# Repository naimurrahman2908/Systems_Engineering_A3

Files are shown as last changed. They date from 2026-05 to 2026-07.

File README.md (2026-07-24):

# 🤖 Line Following and Obstacle Avoidance Robot






---

## 📖 Project Overview

This repository contains the design, implementation, modelling, and testing of an autonomous **Line Following and Obstacle Avoidance Robot** developed as part of the **Systems Engineering** course at **Hochschule Hamm-Lippstadt (HSHL)**.

The robot autonomously follows a predefined black line using infrared (IR) sensors while detecting obstacles with ultrasonic sensors. The project combines embedded software, hardware integration, SysML modelling, and automated technical documentation using LaTeX.

---

## 👥 Team Members

| Member | Responsibility |
|---|---|
| **Naimur Rahman** | Introduction and Objectives |
| **Hany Chowdhury** | System Design and Engineering Approach |
| **Torikul Islam** | Hardware & Software Implementation, Simulation & Testing |
| **Adham Elsaygh** | Challenges and Solutions |

---

# 🎯 Project Objectives

The objectives of this project are to:

- Design an autonomous mobile robot capable of following a black line.
- Detect and avoid obstacles during navigation.
- Reacquire the line after obstacle avoidance.
- Perform an automatic 180° turn after detecting the second obstacle.
- Apply Systems Engineering principles throughout development.
- Model the complete system using SysML.
- Validate the final prototype through experimental testing.

---

# ⭐ Features

- Autonomous Line Following
- Obstacle Detection
- Obstacle Avoidance
- Automatic Line Reacquisition
- 180° Turnaround
- PWM Motor Speed Control
- Embedded Arduino Software
- SysML-Based System Design
- Automated LaTeX Report Generation

---

# 🏗 System Architecture

The robot consists of four major subsystems.

| Subsystem | Components | Function |
|---|---|---|
| Sensing | IR Sensors, Ultrasonic Sensors | Detects the line and obstacles |
| Control | Arduino Uno | Processes sensor data |
| Actuation | L293D Driver, DC Motors | Controls movement |
| Power | 12V Battery | Powers the robot |

---

# 🔧 Hardware Components

- Arduino Uno
- 2 × IR Line Sensors
- 2 × HC-SR04 Ultrasonic Sensors
- L293D Motor Driver
- 2 × DC Geared Motors
- Breadboard
- Wooden Chassis
- 12 V Battery
- Wheels

---

# 🔌 Wiring Connections

## 🔵 Arduino UNO Pin Configuration

| Component | Arduino Pin | Description |
|---|---|---|
| Left IR Sensor | D2 | Left line detection |
| Right IR Sensor | D12 | Right line detection |
| Left Ultrasonic Trigger | D13 | Trigger signal |
| Left Ultrasonic Echo | D4 | Echo signal |
| Right Ultrasonic Trigger | D6 | Trigger signal |
| Right Ultrasonic Echo | D7 | Echo signal |
| Left Motor Enable (ENA) | D3 (PWM) | Speed control |
| Left Motor IN1 | D8 | Motor direction |
| Left Motor IN2 | D9 | Motor direction |
| Right Motor Enable (ENB) | D5 (PWM) | Speed control |
| Right Motor IN3 | D10 | Motor direction |
| Right Motor IN4 | D11 | Motor direction |

---

## ⚡ Power Connections

| Connection | Description |
|---|---|
| 12 V Battery → Motor Driver | Main power supply |
| Motor Driver 5 V → Arduino UNO | Regulated controller power |
| Arduino 5 V → Sensors | Sensor power supply |
| Common Ground | Shared by all components |

> **Important:** All electronic modules share a common ground to ensure stable operation.

---

# 💻 Software Components

- Arduino IDE
- Embedded C++
- Line Following Algorithm
- Obstacle Detection Algorithm
- Obstacle Avoidance Routine
- Line Reacquisition Logic
- Motor Control Functions

---

# 🔄 Robot Operation

The robot operates according to the following sequence:

1. Detect the black line using IR sensors.
2. Read sensor values.
3. Calculate steering direction.
4. Control both motors independently.
5. Continuously monitor obstacles.
6. Detect the first obstacle.
7. Execute obstacle avoidance.
8. Search for and reacquire the line.
9. Continue navigation.
10. Detect the second obstacle.
11. Perform a 180° turn.
12. Continue autonomous operation.

---

# 📊 SysML Models

The project documentation includes:

- Block Definition Diagram (BDD)
- Internal Block Diagram (IBD)
- Use Case Diagram
- Activity Diagram
- Sequence Diagram
- State Machine Diagram
- Package Diagram

---

# 🧪 Testing

The robot was experimentally evaluated using a custom test track with a **2.5 cm black line**, including gentle and sharp curves as well as two obstacles.

### Testing Included

- IR Sensor Validation
- Ultrasonic Sensor Validation
- Motor Verification
- Line Following
- Sharp Curve Tracking
- Gentle Curve Tracking
- Obstacle Avoidance
- Line Reacquisition
- 180° Turn
- Full System Integration

---

## 📈 Performance Summary

| Test | Result |
|---|---|
| Line Following | ✅ Successful |
| Gentle Curves | ✅ Successful |
| Sharp Curves | ✅ Successful |
| First Obstacle Detection | ✅ Successful |
| Obstacle Avoidance | ✅ Successful |
| Line Reacquisition | ✅ Successful |
| Second Obstacle Detection | ✅ Successful |
| 180° Turn | ✅ Successful |
| Complete Trials | **10 / 10** |
| Overall Success Rate | **100%** |

---

# 🛠 Technologies Used

- Arduino IDE
- C++
- GitHub
- GitHub Actions
- LaTeX (IEEE Format)
- SysML
- Visual Paradigm
- Tinkercad

---

# 📁 Repository Structure

```text
Systems_Engineering_A3/
│
├── Codes/
│
├── Prototype_Design/
│
├── SysML_Diagrams/
│
├── Tinkercad_Design/
│
└── LineFollowingRobot_Report/
    ├── figures/
    ├── sections/
    ├── main.tex
    └── report.pdf
```

---

# 📄 Report Compilation

The project documentation is written in **LaTeX** using the IEEE Conference format.

GitHub Actions automatically:

- Builds the report
- Compiles the PDF
- Commits the latest report
- Keeps documentation up to date

---

# 📚 Latest Report

The latest IEEE report is available below.

➡️ **[Download PDF Report](./LineFollowingRobot_Report/report.pdf)**

---

# 🚀 Future Improvements

Potential future enhancements include:

- PID Controller
- Wireless Communication
- Bluetooth Monitoring
- Wi-Fi Connectivity
- Camera-Based Navigation
- Machine Learning
- Real-Time Telemetry
- Improved Chassis Design
- Battery Monitoring

---

# 🎓 Course Information

| Item | Details |
|---|---|
| Course | Systems Engineering |
| Degree | Electronic Engineering |
| University | Hochschule Hamm-Lippstadt |
| Semester | Summer Semester 2026 |

---

# 📜 License

This repository was developed for academic purposes as part of the **Systems Engineering** course at **Hochschule Hamm-Lippstadt**.

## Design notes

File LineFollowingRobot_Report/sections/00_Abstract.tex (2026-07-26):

\begin{abstract}
This paper presents a low-cost line-following and obstacle-avoidance robot built on an Arduino Uno. Two IR sensors enable line tracking, while two HC-SR04 ultrasonic sensors handle obstacle detection; an L293D motor driver controls the two DC motors. Prior to construction, a systems engineering approach using SysML diagrams (block definition, internal block, activity, sequence, use case, and state machine) modeled the robot's structure and behavior. The design follows a track, avoids the first detected obstacle, then performs a 180° turn at a second obstacle before retracing the line in reverse. Testing on a custom track with curves and obstacles yielded a 100 percent success rate across 10 trials, confirming reliable performance.
\end{abstract}

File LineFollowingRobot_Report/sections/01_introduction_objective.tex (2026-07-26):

\section{Introduction and Objective}
\label{sec:introduction and objective}
\subsection{Introduction}

Automated Guided Vehicles (AGVs) are smart, driverless vehicles that bring the speed and precision of modern automation to material handling. By using advanced embedded systems to navigate safely and adapt in real time, they turn manual logistics into a predictable, data-driven backbone for Industry 4.0 [1, 2]. 

Line following and collision avoidance serve as the fundamental navigation and safety pillars. Together, these embedded subsystems ensure the AGV can optimize space by working seamlessly alongside human workers while strictly complying with industrial safety standards like ISO 3691-4. 

This project focuses on the systems engineering, prototyping, and development of a compact, microcontroller-driven autonomous vehicle designed for precise trajectory tracking and proactive collision mitigation. 

\subsection{Objective}

The primary goal of this project is to implement, test, and validate a working prototype of an autonomous mobile vehicle using model-based prototyping principles. To meet the course milestones, the system must achieve the following specific technical objectives:
\begin{itemize}
    \item {Line Following:} Use a set of infrared (IR) sensors and standard if-else logic to control the motors so the car cleanly follows a track line.
    \item {Obstacle Detection and Avoidance:} Integrate a pair of ultrasonic sensors to monitor front proximity metrics and implement a maneuver sequence to safely bypass detected obstructions before reacquiring the primary track line.
    \item {Secondary Obstacle Detection and Turnaround:} Program the car to use its front ultrasonic sensors to detect a second obstacle along the path, stop moving forward, spin 180 degrees on the spot, and follow the track back in the opposite direction.
    \item {Power and Motor Integration:} Wire the hardware so that a motor controller takes a 12V battery source, drops it down to 5V to safely power the Arduino, and handles the high-current demands of the DC motors.
\end{itemize}

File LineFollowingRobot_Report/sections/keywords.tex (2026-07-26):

\begin{IEEEkeywords}
    Line follower robot, IR sensor, Ultrasonic sensor, Arduino, Obstacle avoidance, DC motor
\end{IEEEkeywords}

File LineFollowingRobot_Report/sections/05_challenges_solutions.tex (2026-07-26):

\section{Challenges and Solutions}
\label{sec:challenges_solutions}
During the engineering and prototyping phases, several technical challenges were encountered across the hardware and software subsystems. 
These obstacles were systematically resolved through testing, software adjustments, and control refinements.  

A. Motor Speed Inconsistency and Straight-Line Drift
A primary physical challenge involved mechanical and electrical variances between the two DC motors. When driven with identical pulse-width modulation (PWM) signals, differences in motor resistance and internal gear friction caused the robot to drift off course rather than moving straight.  

Solution: To achieve balanced linear movement, a software calibration procedure was performed using trial and error. By iteratively tuning and assigning individual offset PWM values to each motor, the rotational speeds were balanced to ensure straight-line movement.

B. Track Detection Strategy
During line-following testing, initial attempts were made to navigate by tracking the white boundary outline surrounding the black track. However, this approach resulted in inconsistent sensor readings. Testing confirmed that tracking the solid black line directly produced significantly better results.

Solution: The control logic and tracking strategy were reconfigured to target the solid black line directly. This adjustment provided higher contrast for the infrared sensors, leading to more reliable line tracking 
and smoother steering responses.

C. Ultrasonic Sensor Noise and Ghost Obstacles
During proximity measurement, the HC-SR04 ultrasonic sensors occasionally received false echo reflections from surrounding walls and non-target surfaces. This noise created "ghost obstacles," resulting in false-positive detections that caused the robot to stop prematurely.

Solution: Software-level signal filtering was integrated into the obstacle-detection routine. The control algorithm was programmed to prouduce 2 consecutive range readings before triggering an action, ensuring avoidance maneuvers were only executed when a real obstacle was confirmed.

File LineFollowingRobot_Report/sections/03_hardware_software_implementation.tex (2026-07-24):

\section{Hardware Software Implementation}
\label{sec:hardware_software_implementation}

\subsection{Hardware Implementation}

The developed prototype consists of a compact autonomous mobile robot capable of line following and obstacle avoidance. The system integrates sensing, control, actuation, and power management into a single embedded platform. Figure~\ref{fig:robot} shows the completed robot prototype used during implementation and testing.

The Arduino Uno microcontroller serves as the central controller of the robot. It continuously receives data from two infrared (IR) sensors and two HC-SR04 ultrasonic sensors, processes the sensor information, and generates motor control commands. The IR sensors are mounted at the front of the robot to detect the black line, while the ultrasonic sensors continuously monitor the distance to obstacles during navigation.

An L293D motor driver is used to control two DC geared motors. The motor driver receives PWM signals from the Arduino and regulates the speed and direction of both motors. To compensate for mechanical differences between the motors, calibrated PWM values were applied to obtain stable straight-line movement.

The complete system is powered by a 12\,V battery. The motor driver supplies a regulated 5\,V output to power the Arduino Uno and the connected sensors. This configuration provides a simple and reliable power distribution while maintaining stable operation of both the electronic and mechanical components.

The electronic components are mounted on a lightweight wooden chassis using a breadboard for rapid prototyping. This modular arrangement simplifies wiring, maintenance, and future hardware modifications.

\begin{table}[ht]
\caption{Hardware Components}
\centering
\begin{tabular}{lll}
\hline
\textbf{Component} & \textbf{Qty} & \textbf{Purpose} \\
\hline
Arduino Uno & 1 & Main controller \\
L293D Motor Driver & 1 & Motor control \\
DC Motors & 2 & Robot movement \\
IR Sensors & 2 & Line detection \\
HC-SR04 Sensors & 2 & Obstacle detection \\
Breadboard & 1 & Circuit prototyping \\
12\,V Battery & 1 & Power supply \\
Wooden Chassis & 1 & Mechanical support \\
\hline
\end{tabular}
\label{tab:hardware}
\end{table}

\begin{figure}[ht]
\centering
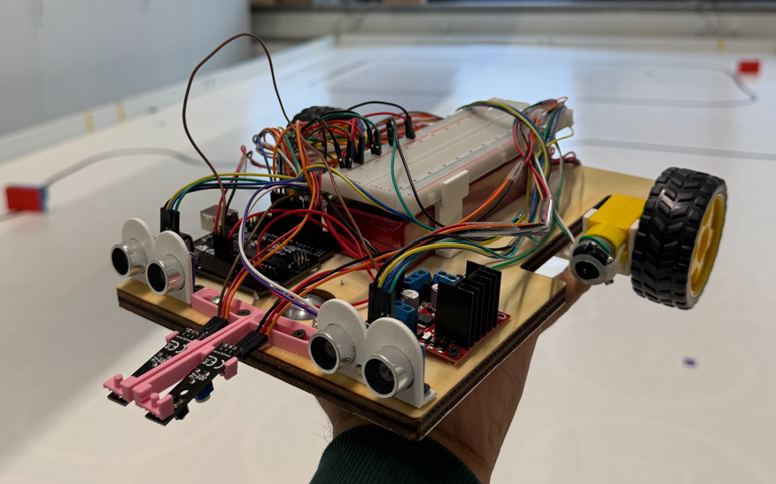
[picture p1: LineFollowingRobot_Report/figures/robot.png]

\caption{Final hardware prototype of the autonomous line-following and obstacle-avoidance robot.}
\label{fig:robot}
\end{figure}

\subsection{Software Implementation}

The control software was developed using the Arduino Integrated Development Environment (Arduino IDE) in C++. A modular programming approach was adopted to separate sensor acquisition, motor control, obstacle detection, and navigation into independent software functions. This improves readability, simplifies debugging, and allows future system extensions.

During initialization, the Arduino configures all digital input and output pins, initializes the infrared and ultrasonic sensors, and enables the motor driver. After initialization, the software repeatedly executes the main control loop throughout the robot's operation.

The first stage of the control algorithm continuously checks the ultrasonic sensors for nearby obstacles. When an obstacle is detected within the predefined safety distance, the robot immediately stops and confirms the measurement before executing the obstacle avoidance routine.

If no obstacle is detected, the robot performs line following using the two infrared sensors. Based on the sensor readings, the controller determines whether the robot should move forward, turn left, or turn right. Independent PWM control of the two motors enables smooth steering corrections while following the track.

To improve navigation reliability, the software stores the previous movement direction. If both infrared sensors temporarily lose the line, the robot searches in the last known direction until the track is detected again. After avoiding an obstacle, the robot continues searching until the line is reacquired before resuming normal navigation.

Overall, the implemented software provides reliable autonomous operation while maintaining a computationally efficient control strategy suitable for embedded systems.

\subsection{Hardware--Software Integration}

The hardware and software operate together as a closed-loop embedded system. Sensor information collected by the infrared and ultrasonic sensors is processed by the Arduino Uno, which determines the appropriate movement commands. These commands are transmitted to the L293D motor driver, which controls the speed and direction of the two DC motors.

The continuous interaction between sensing, processing, and actuation enables the robot to follow a predefined path, detect obstacles, execute avoidance manoeuvres, and return to the original track without external intervention. The implementation demonstrates that reliable autonomous behaviour can be achieved using low-cost hardware combined with an efficient embedded control algorithm.

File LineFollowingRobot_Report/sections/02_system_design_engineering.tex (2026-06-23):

\section{System Design and Engineering Approach}
\label{sec:system_design_engineering}
\subsection{System Overview}

The Line Following Robot is an autonomous system designed to follow a predefined path while detecting obstacles during operation. The system combines sensing, control, and actuation components to achieve reliable navigation. A systems engineering approach was applied throughout the project to identify requirements, define subsystem interactions, and develop an organized system architecture before implementation.

The robot consists of four main subsystems: the sensing subsystem, control subsystem, actuation subsystem, and power subsystem. These subsystems work together to support autonomous movement and obstacle detection.

\subsection{System Architecture}

A Block Definition Diagram (BDD) was created to represent the main components of the robot and their relationships. The diagram provides an overview of how the sensing, control, movement, and power elements are organized within the system.

\begin{figure}[htbp]
\centering
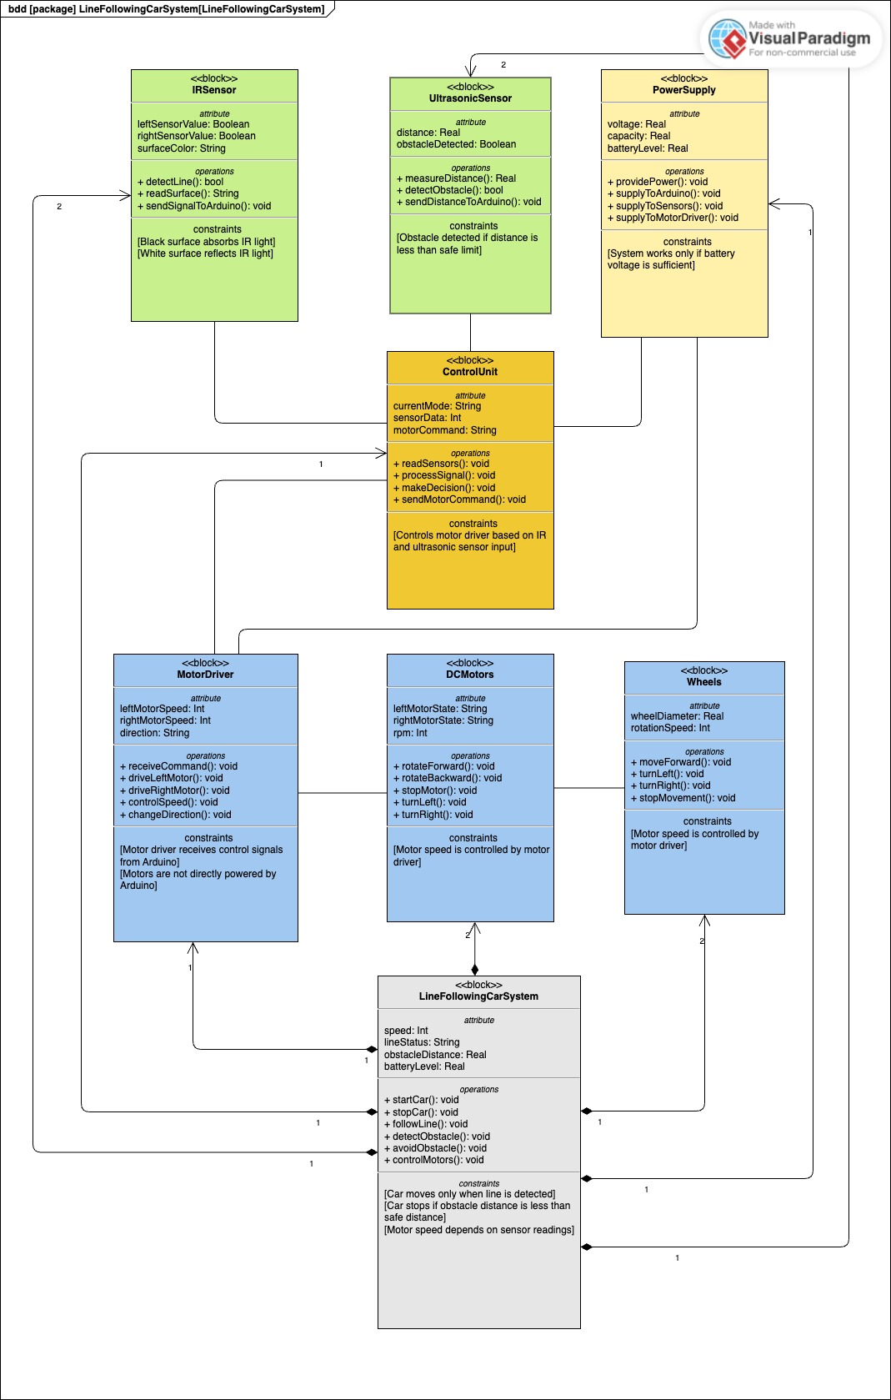
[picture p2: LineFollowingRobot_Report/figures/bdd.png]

\caption{Block Definition Diagram of the Line Following Robot}
\label{fig:bdd}
\end{figure}
\FloatBarrier

The sensing subsystem includes infrared (IR) sensors for line detection and ultrasonic sensors for obstacle detection. The control subsystem is based on the Arduino Uno microcontroller, which processes sensor information and determines the required motor actions. The actuation subsystem consists of the L293D motor driver and two DC motors that provide movement. The power subsystem supplies electrical energy to all hardware components.

\subsection{Internal Component Interaction}

An Internal Block Diagram (IBD) was developed to illustrate the connections and interactions between system components. The diagram shows how information and control signals are exchanged within the robot.

\begin{figure}[htbp]
\centering
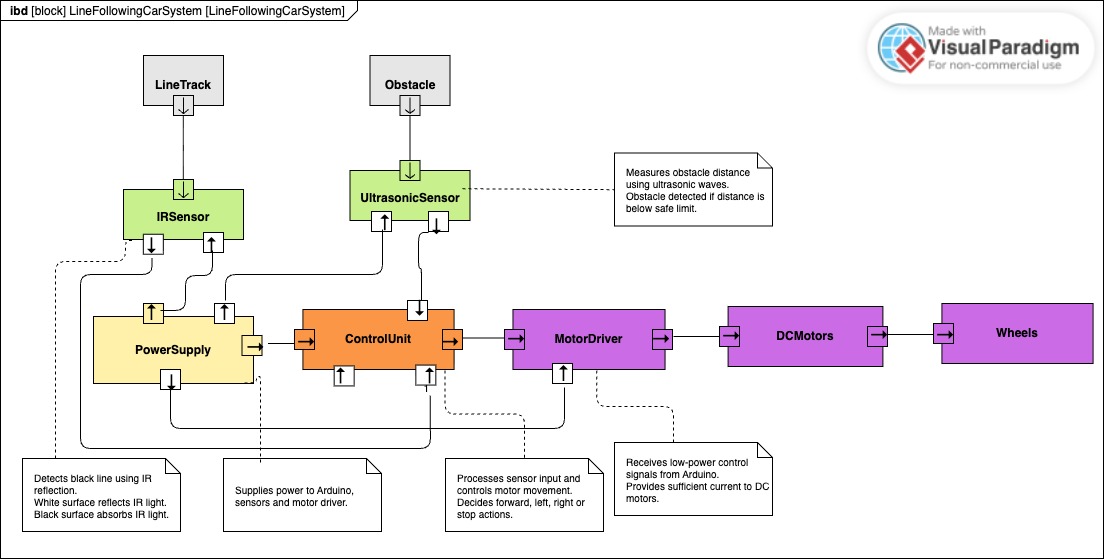
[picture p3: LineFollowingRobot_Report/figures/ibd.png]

\caption{Internal Block Diagram}
\label{fig:ibd}
\end{figure}
\FloatBarrier

The IR sensors continuously monitor the line position and send data to the Arduino controller. At the same time, the ultrasonic sensors measure the distance to nearby obstacles. Based on these inputs, the Arduino generates appropriate control signals for the motor driver, which adjusts the speed and direction of the motors.

\subsection{Functional Behaviour}

The behaviour of the robot was analysed using system modelling techniques. An Activity Diagram was created to describe the overall operational workflow.

\begin{figure}[htbp]
\centering
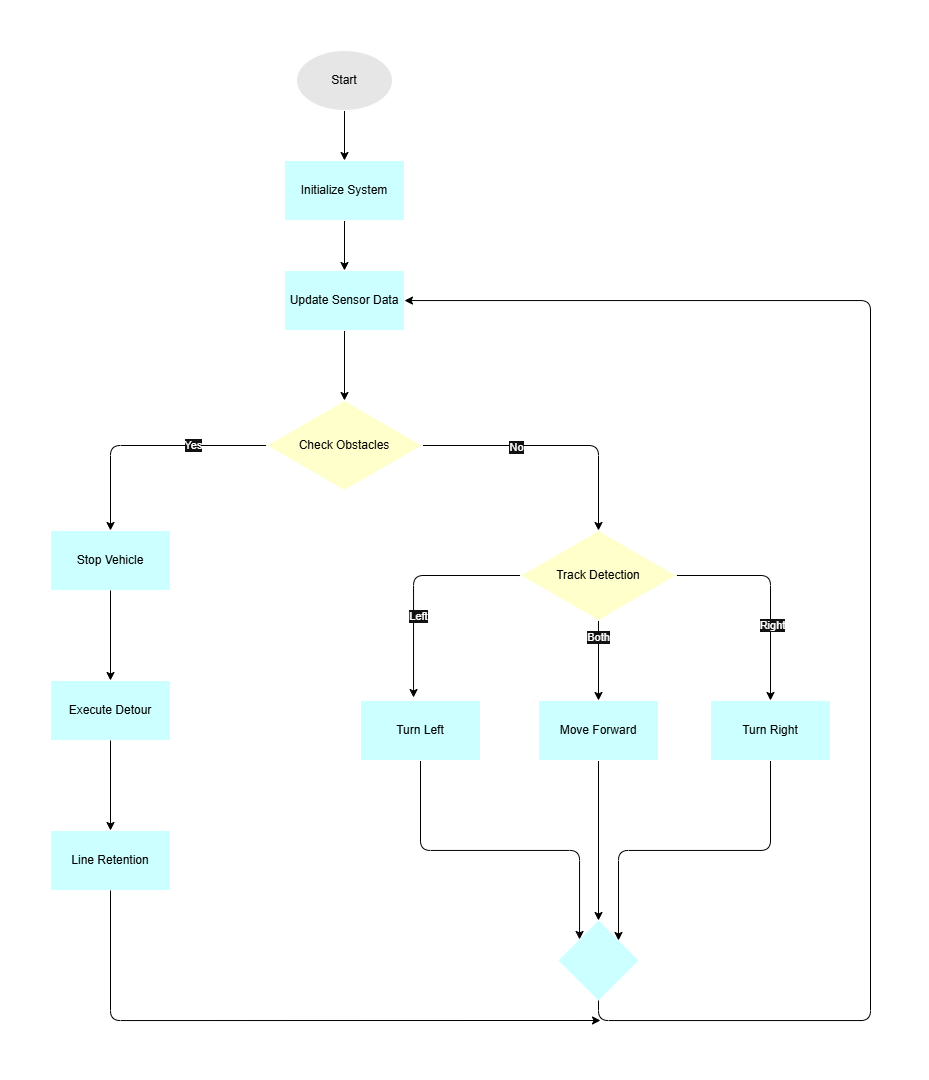
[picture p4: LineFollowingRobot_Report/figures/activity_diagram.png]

\caption{Activity Diagram}
\label{fig:activity}
\end{figure}
\FloatBarrier

The process begins with system initialization. The robot then continuously reads sensor data, evaluates the position of the line and the presence of obstacles, determines the required action, and updates motor commands. This cycle is repeated throughout operation.

A Sequence Diagram was also developed to represent the interaction between system components during robot operation.

\begin{figure}[htbp]
\centering
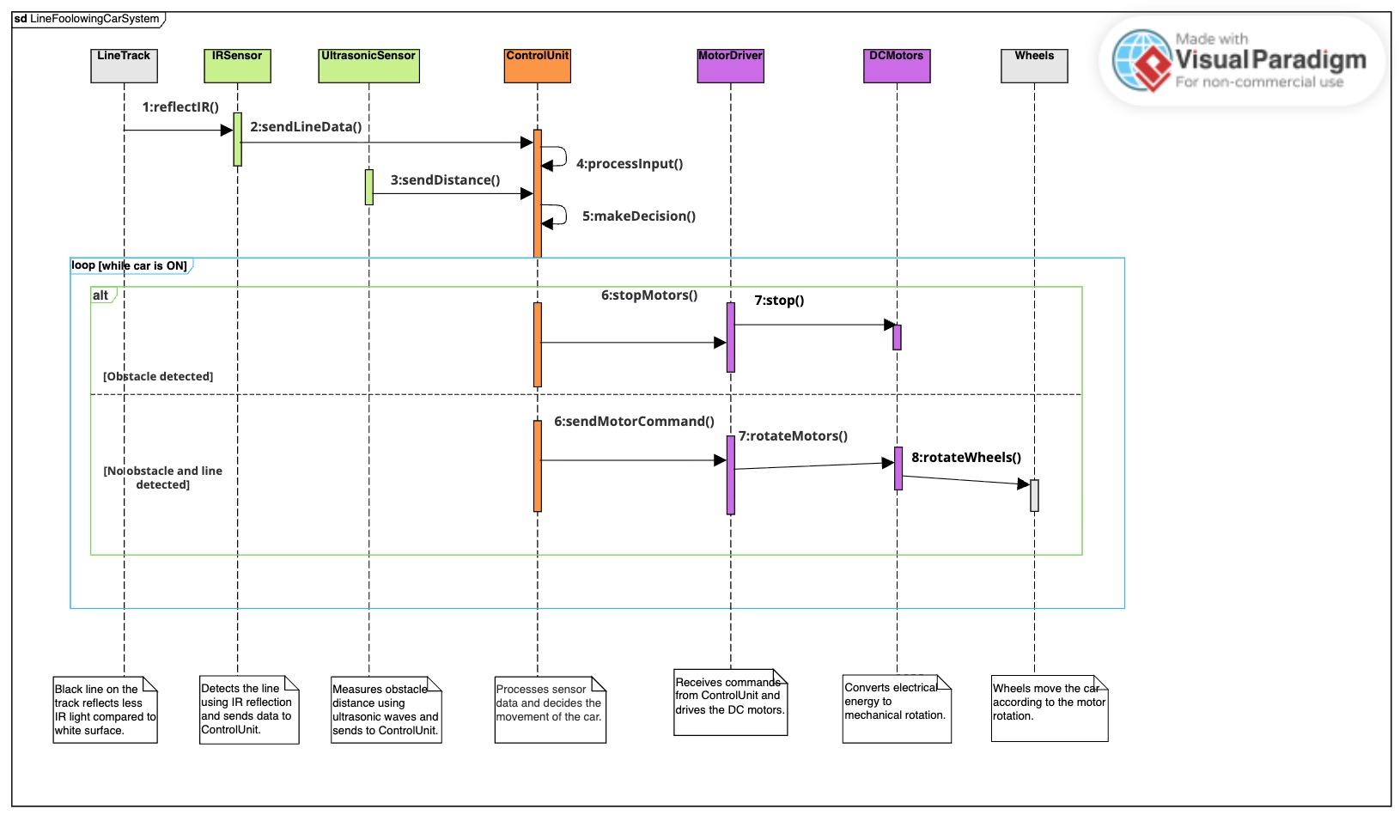
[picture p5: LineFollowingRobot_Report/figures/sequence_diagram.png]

\caption{Sequence Diagram}
\label{fig:sequence}
\end{figure}
\FloatBarrier

The sequence diagram illustrates how information is exchanged between the sensors, controller, and actuators during line-following and obstacle-detection activities.

\subsection{Use Case Analysis}

A Use Case Diagram was developed to identify the main functions of the robot from the user’s perspective.

\begin{figure}[htbp]
\centering
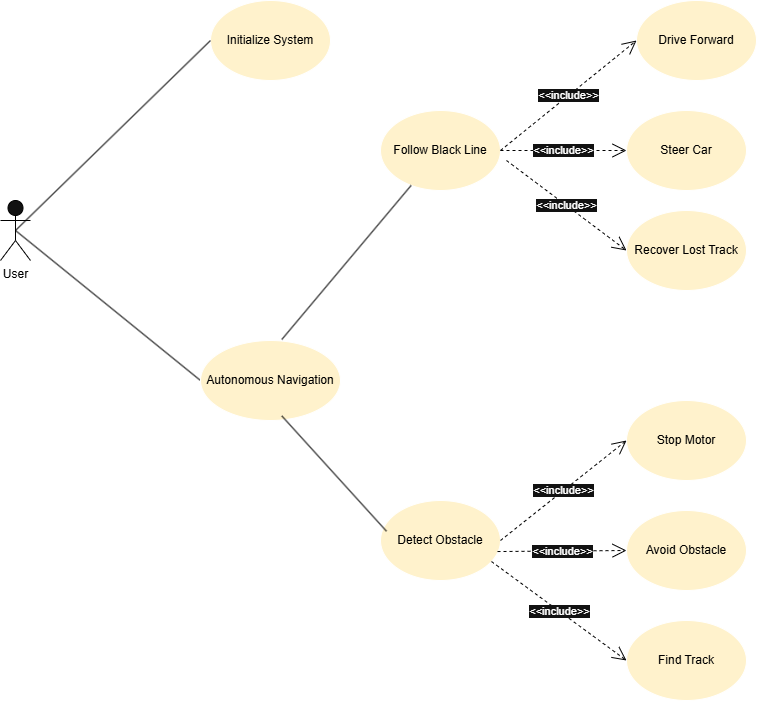
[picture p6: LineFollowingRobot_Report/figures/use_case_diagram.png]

\caption{Use Case Diagram}
\label{fig:usecase}
\end{figure}
\FloatBarrier

The main use cases include starting the robot, following the line, detecting obstacles, controlling movement, and stopping the robot. These functions represent the primary operational requirements of the system.

\subsection{System States}

A State Machine Diagram was created to model the different operational states of the robot.

\begin{figure}[htbp]
\centering
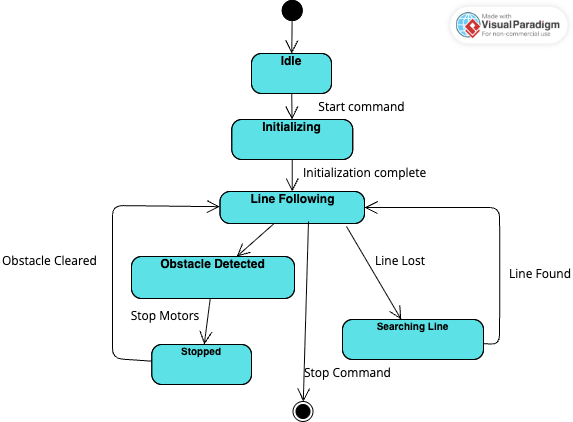
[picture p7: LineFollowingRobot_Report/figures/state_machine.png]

\caption{State Machine Diagram}
\label{fig:state}
\end{figure}
%\FloatBarrier

The robot initially remains in the Idle state. Once activated, it transitions to the Line Following state. When an obstacle is detected, the system moves to the Obstacle Detected state and performs a stop or avoidance action. After the obstacle is cleared, the robot returns to normal operation.

\subsection{Design Decisions}

Several design decisions were made during the development of the prototype. The Arduino Uno was selected because it is easy to program, widely supported, and compatible with various sensors and motor drivers. IR sensors were chosen for accurate line detection, while ultrasonic sensors were used to provide reliable obstacle detection. The L293D motor driver was selected because it allows simple and effective control of two DC motors.

The use of SysML diagrams improved system understanding by providing both structural and behavioural views of the robot. These models supported the implementation process and helped ensure consistency between system requirements and the final prototype design.

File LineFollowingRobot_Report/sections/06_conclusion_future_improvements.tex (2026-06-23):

\section{Conclusion and Future Improvements}
\label{sec:conclusion_future_improvements}
\subsection{Conclusion}

This project successfully demonstrated the design and development of a Line Following Robot capable of autonomous navigation and obstacle detection. By integrating infrared sensors, ultrasonic sensors, an Arduino Uno microcontroller, and a motor control system, the robot was able to follow a predefined path while responding to environmental conditions.

A systems engineering approach was applied throughout the project to support requirement identification, system modelling, implementation, and testing. The use of SysML diagrams provided a clear representation of both the structural and behavioural aspects of the system, helping to improve understanding of component interactions and overall system functionality.

The testing results showed that the robot was able to perform the intended line-following and obstacle-detection tasks under normal operating conditions. Therefore, the project achieved its primary objective of developing a functional robotic prototype while applying key systems engineering principles.

\subsection{Future Improvements}

Although the prototype met the project requirements, several improvements could be implemented in future developments. One possible enhancement is the integration of a PID control algorithm to improve movement accuracy and provide smoother line-following performance. Additional infrared sensors could also be incorporated to increase detection reliability, particularly when navigating sharp curves or complex paths.

The mechanical design could be further optimized by improving chassis stability, wheel alignment, and component placement. These modifications may contribute to better overall performance and durability of the robot.

Furthermore, wireless communication technologies such as Bluetooth or Wi-Fi could be added to enable remote monitoring and control. Future versions may also incorporate camera-based vision systems or machine learning techniques to support more advanced navigation and obstacle-avoidance capabilities.

Overall, the proposed improvements would increase the robot’s accuracy, adaptability, and functionality, making it more suitable for complex autonomous applications.

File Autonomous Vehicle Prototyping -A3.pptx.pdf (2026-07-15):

# Line Following & Obstacle Avoidance Control

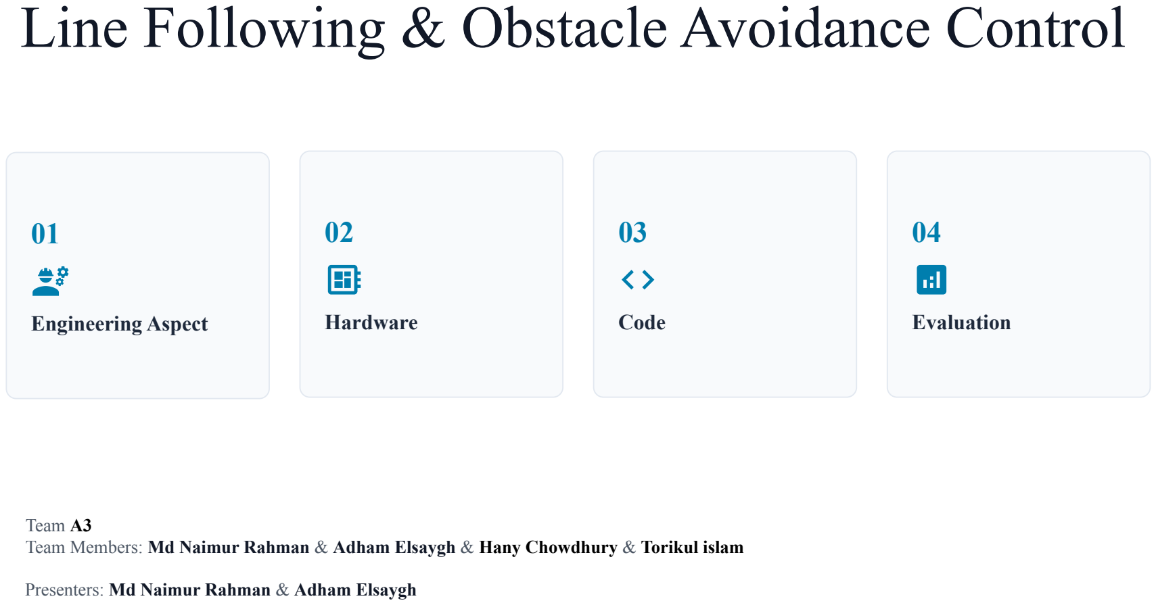
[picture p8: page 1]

01

## Engineering Aspect

02

## Hardware

03

## Code

04

## Evaluation

Presenters: Md Naimur Rahman & Adham Elsaygh

Team A3
Team Members: Md Naimur Rahman & Adham Elsaygh & Hany Chowdhury & Torikul islam

# Systems Engineering Aspect

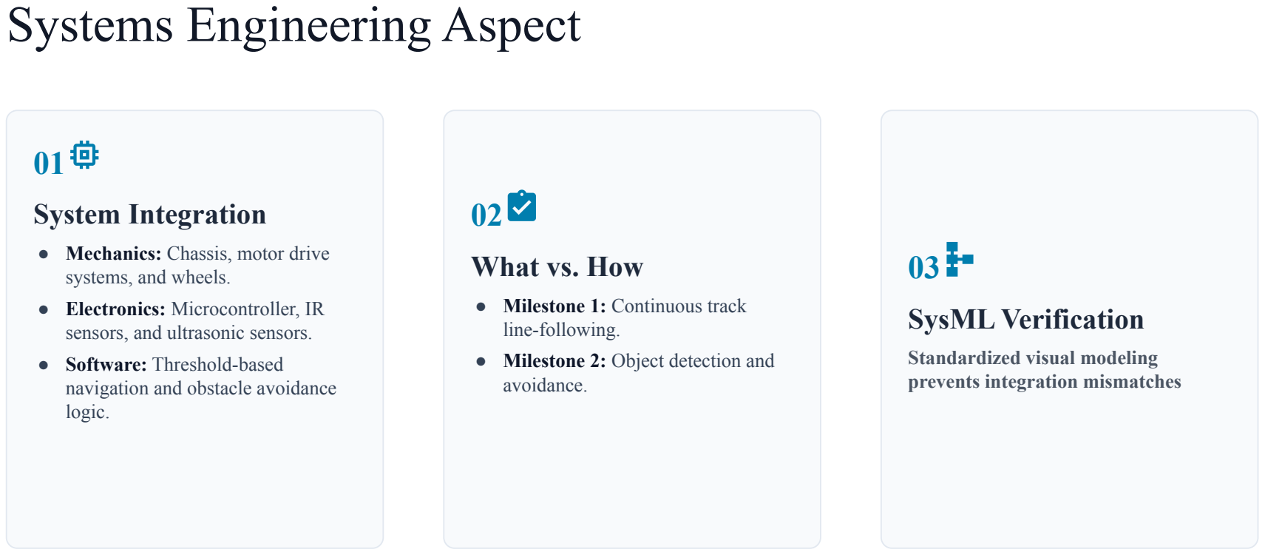
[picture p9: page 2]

01

## System Integration

- Mechanics: Chassis, motor drive systems, and wheels.
- Electronics: Microcontroller, IR sensors, and ultrasonic sensors.
- Software: Threshold-based navigation and obstacle avoidance logic.

02

## What vs. How

- Milestone 1: Continuous track line-following.
- Milestone 2: Object detection and avoidance.

03

## SysML Verification

Standardized visual modeling prevents integration mismatches

# Hardware Setup & Integration

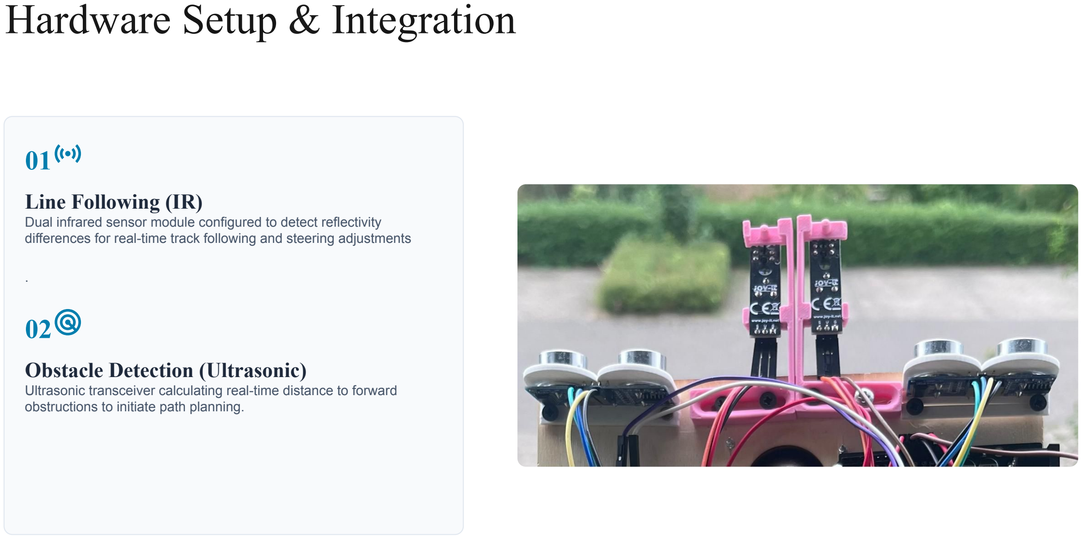
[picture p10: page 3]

01

## Line Following (IR)

Dual infrared sensor module configured to detect reflectivity differences for real-time track following and steering adjustments

02

## Obstacle Detection (Ultrasonic)

Ultrasonic transceiver calculating real-time distance to forward obstructions to initiate path planning.

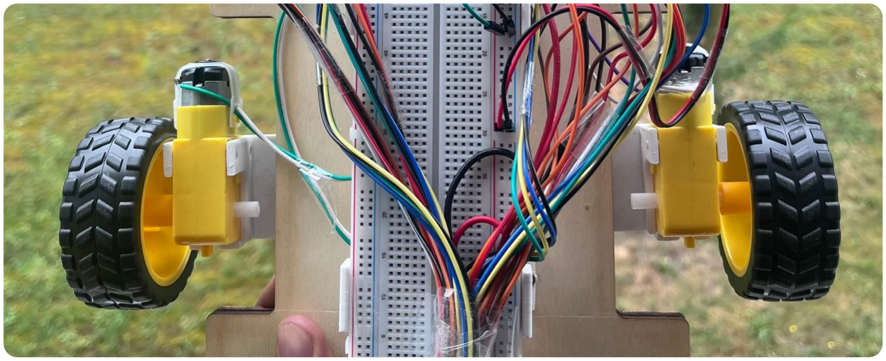
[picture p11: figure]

03

## Motor Setup

High-torque DC motors configured for precise speed and directional mobility.

04

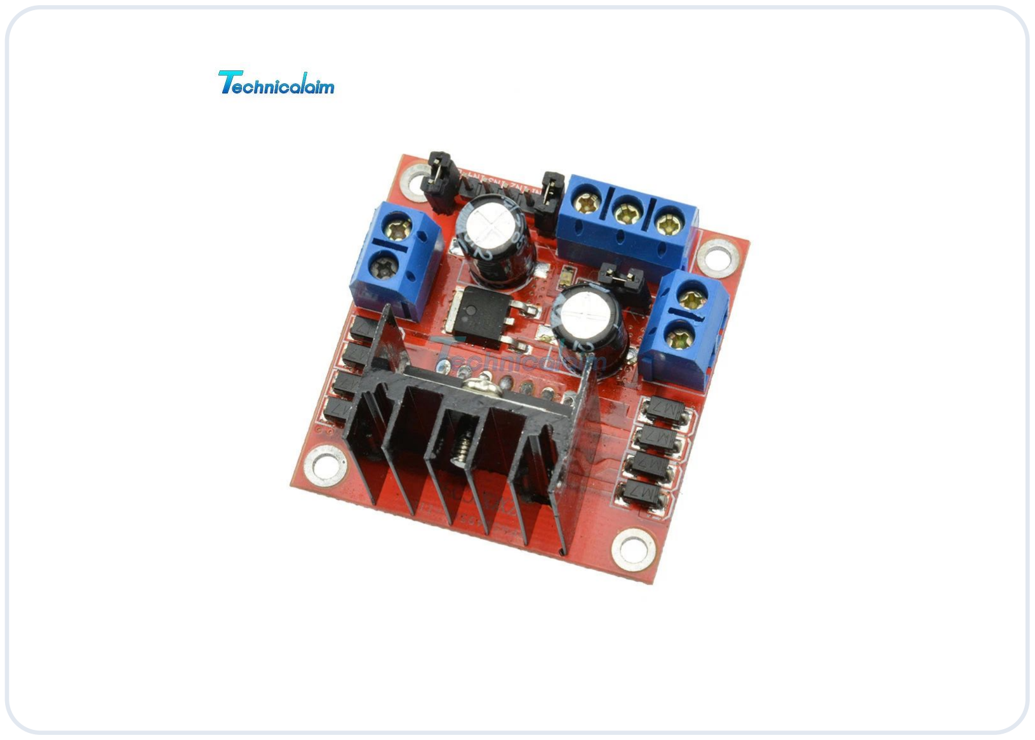
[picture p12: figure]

## Motor Driver (L298N)

Dual-channel H-bridge controller managing voltage and direction for the drive system.

05

## Voltage Regulation Flow

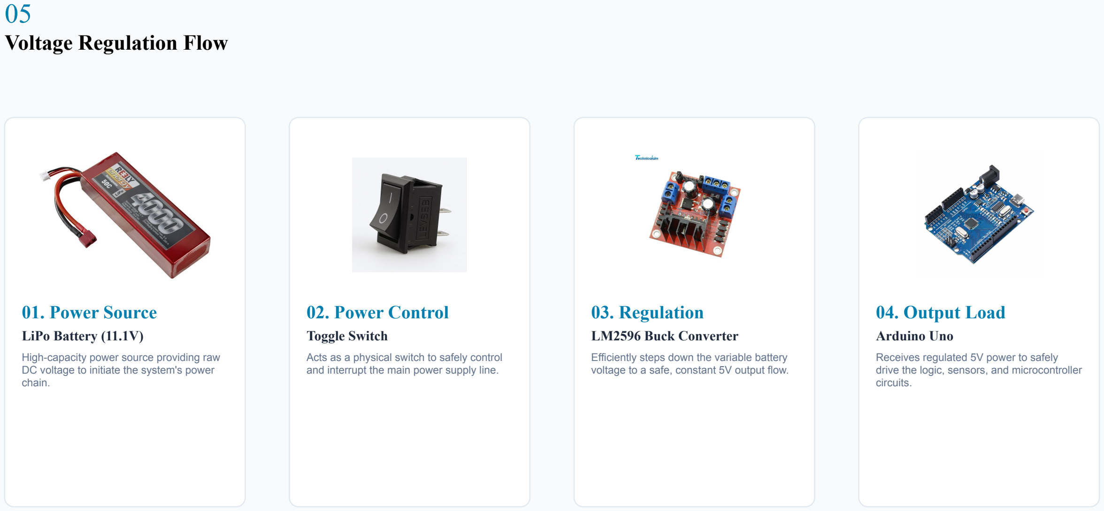
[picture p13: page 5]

### 01. Power Source

LiPo Battery (11.1V)

High-capacity power source providing raw DC voltage to initiate the system's power chain.

### 02. Power Control

Toggle Switch

Acts as a physical switch to safely control and interrupt the main power supply line.

### 03. Regulation

LM2596 Buck Converter

Efficiently steps down the variable battery voltage to a safe, constant 5V output flow.

### 04. Output Load

Arduino Uno

Receives regulated 5V power to safely drive the logic, sensors, and microcontroller circuits.

# Code Implementation

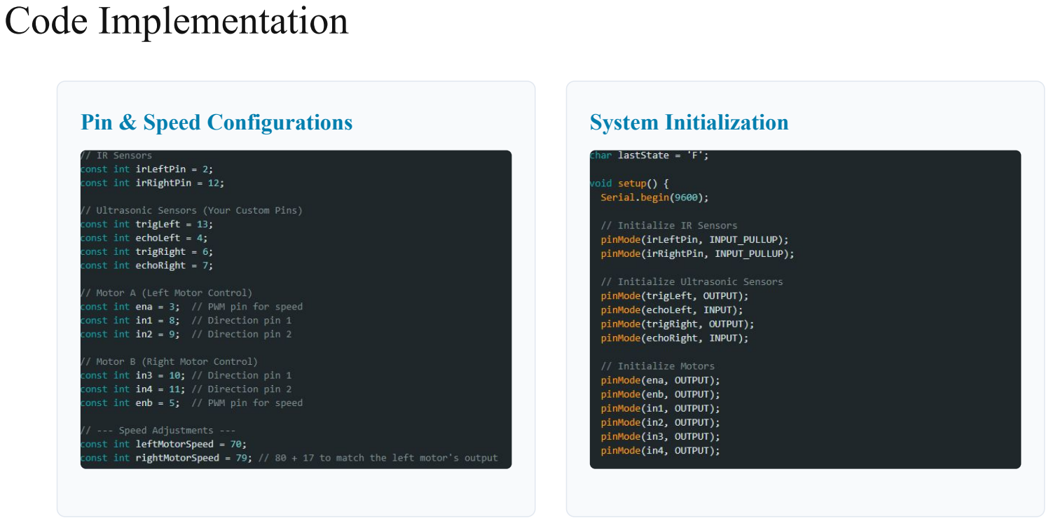
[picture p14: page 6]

Pin & Speed Configurations | System Initialization

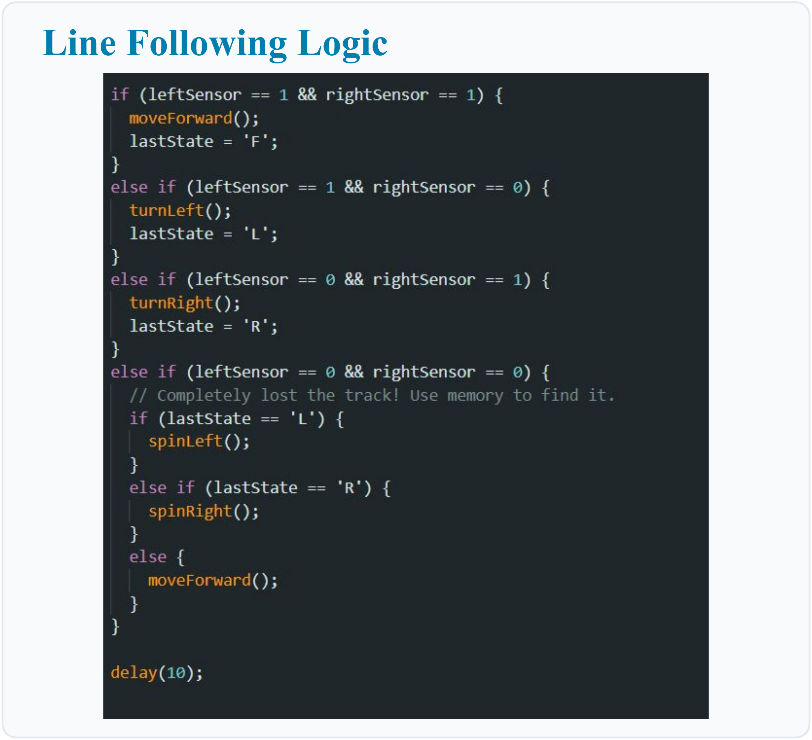
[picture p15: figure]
Line Following Logic

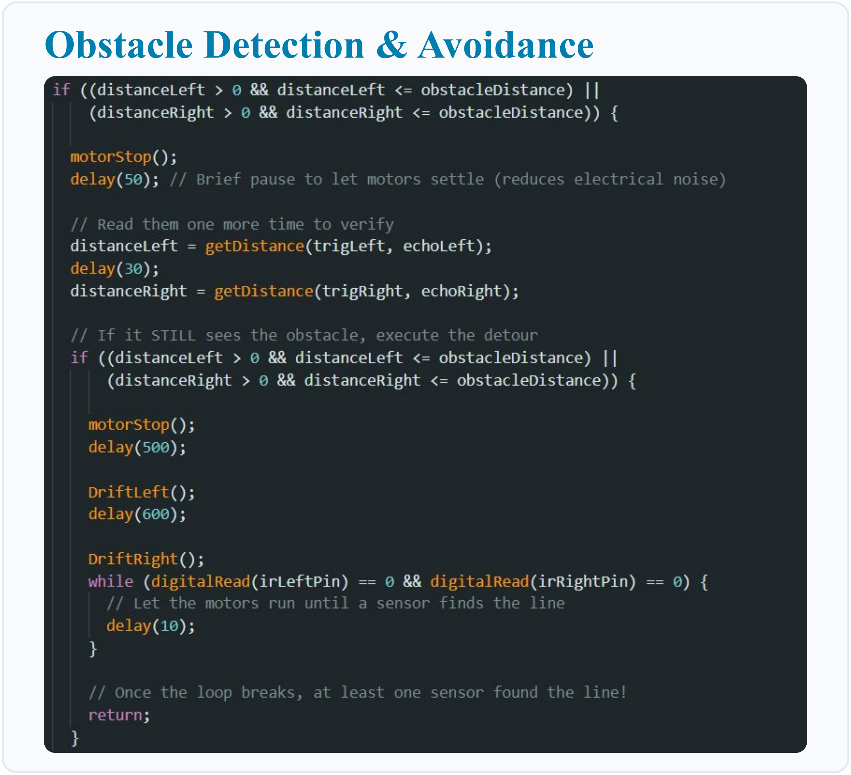
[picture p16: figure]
Obstacle Detection & Avoidance

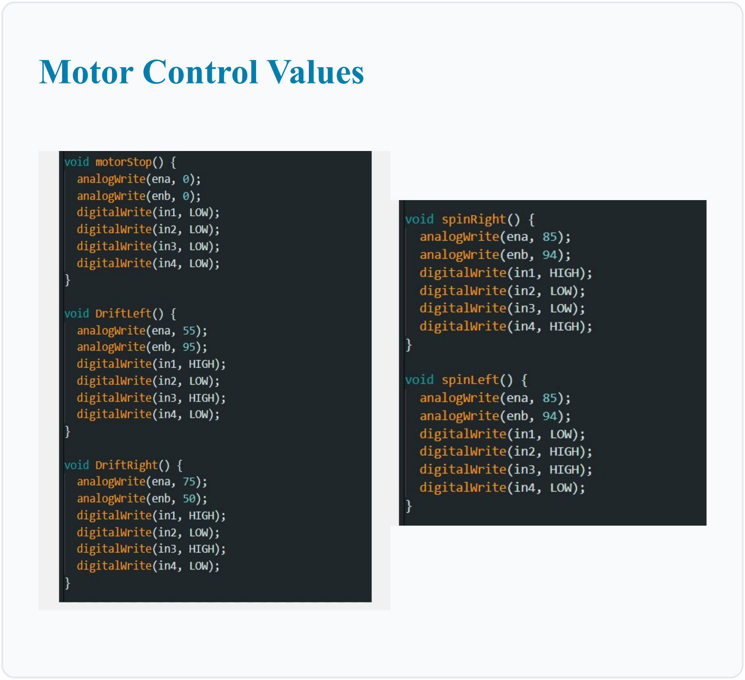
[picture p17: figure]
Motor Control Values

# Testing and Evaluation

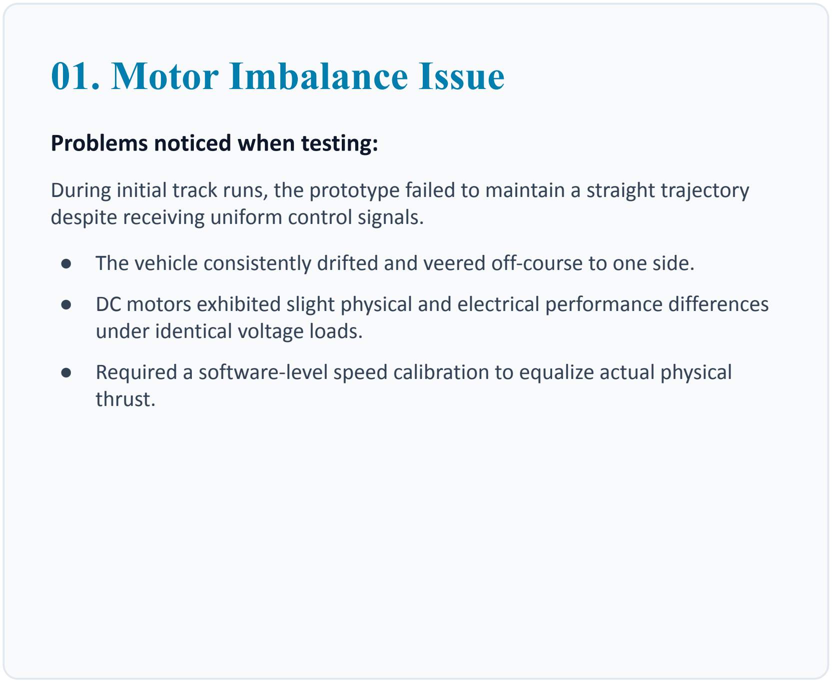
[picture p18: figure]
01. Motor Imbalance Issue; Problems noticed when testing:; despite receiving uniform control signals.; under identical voltage loads.; thrust.

During initial track runs, the prototype failed to maintain a straight trajectory

- The vehicle consistently drifted and veered off-course to one side.
- DC motors exhibited slight physical and electrical performance differences
- Required a software-level speed calibration to equalize actual physical

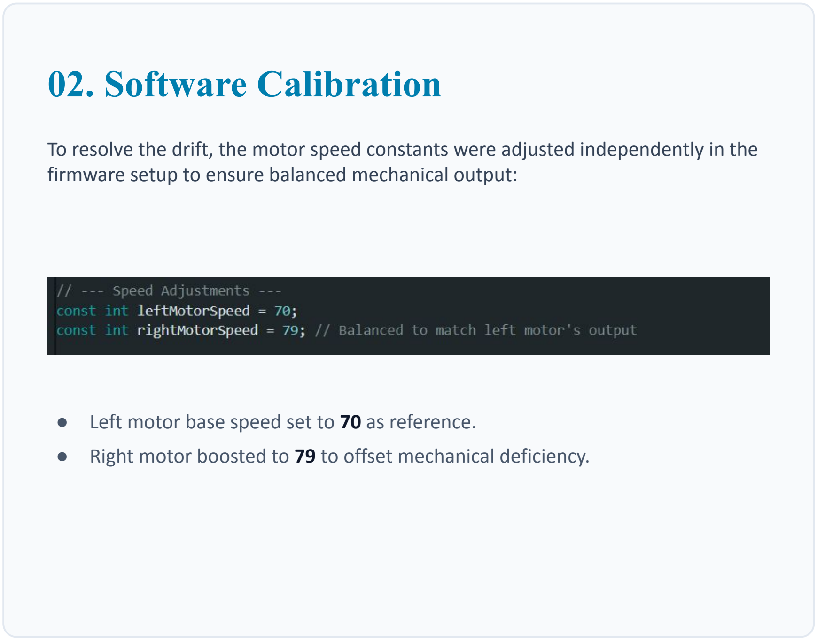
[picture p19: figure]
02. Software Calibration

To resolve the drift, the motor speed constants were adjusted independently in the firmware setup to ensure balanced mechanical output:

- Left motor base speed set to 70 as reference.
- Right motor boosted to 79 to offset mechanical deficiency.

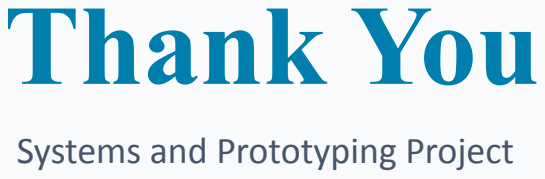
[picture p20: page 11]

# Thank You

## Systems and Prototyping Project

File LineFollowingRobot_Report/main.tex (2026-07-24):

% !TeX program = latexmk
% !TeX root = main.tex
\documentclass[conference]{IEEEtran}

\usepackage[T1]{fontenc}
\usepackage[utf8]{inputenc}
\usepackage{cite}
\usepackage{amsmath,amssymb,amsfonts}
\usepackage{graphicx}
\usepackage{textcomp}
\usepackage{xcolor}
\usepackage{booktabs}
\usepackage{siunitx}
\usepackage{url}
\usepackage[hidelinks]{hyperref}
\usepackage{array}
\usepackage[top=2cm,left=2cm,right=1.5cm,bottom=2cm]{geometry}
\usepackage{float}
\usepackage{tikz}
\usepackage{placeins}
\usetikzlibrary{positioning,shapes.geometric,arrows.meta}

\graphicspath{{figures/}}
\bibliographystyle{IEEEtran}
\hypersetup{
    colorlinks=true,
    linkcolor=blue,
    citecolor=blue,
    urlcolor=blue
}

% -------------------------------------------------------------------

\begin{document}

    \title{Design and Implementation of a Line Following and Obstacle Avoidance Robot}

    \author{
        \IEEEauthorblockN{1\textsuperscript{st} Md Naimur Rahman}
        \IEEEauthorblockA{
            Hochschule Hamm-Lippstadt\\
            Lippstadt, Germany\\
            md-naimur.rahman@stud.hshl.de
        }
        \and
        \IEEEauthorblockN{2\textsuperscript{nd} Hany Chowdhury}
        \IEEEauthorblockA{
            Hochschule Hamm-Lippstadt\\
            Lippstadt, Germany\\
            hany.chowdhury@stud.hshl.de
        }
        \and
        \IEEEauthorblockN{3\textsuperscript{rd} Torikul Islam}
        \IEEEauthorblockA{
            Hochschule Hamm-Lippstadt\\
            Lippstadt, Germany\\
            torikul.islam@stud.hshl.de
        }
        \and
        \IEEEauthorblockN{4\textsuperscript{th} Adham Elsaygh}
        \IEEEauthorblockA{
            Hochschule Hamm-Lippstadt\\
            Lippstadt, Germany\\
            adham.elsaygh@stud.hshl.de
        }
    }

    \maketitle
    \thispagestyle{plain}
    \pagestyle{plain}
    \pagenumbering{arabic}
    \setcounter{page}{1}

    \vspace{0.5em}

% -------------------------------------------------------------------

 \input{sections/00_Abstract}
 
 \input{sections/keywords}
    
\input{sections/01_introduction_objective}

\input{sections/02_system_design_engineering}

\input{sections/03_hardware_software_implementation}

\input{sections/04_simulation_testing_results}

\input{sections/05_challenges_solutions}

\input{sections/06_conclusion_future_improvements}

\input{sections/07_references}

\end{document}

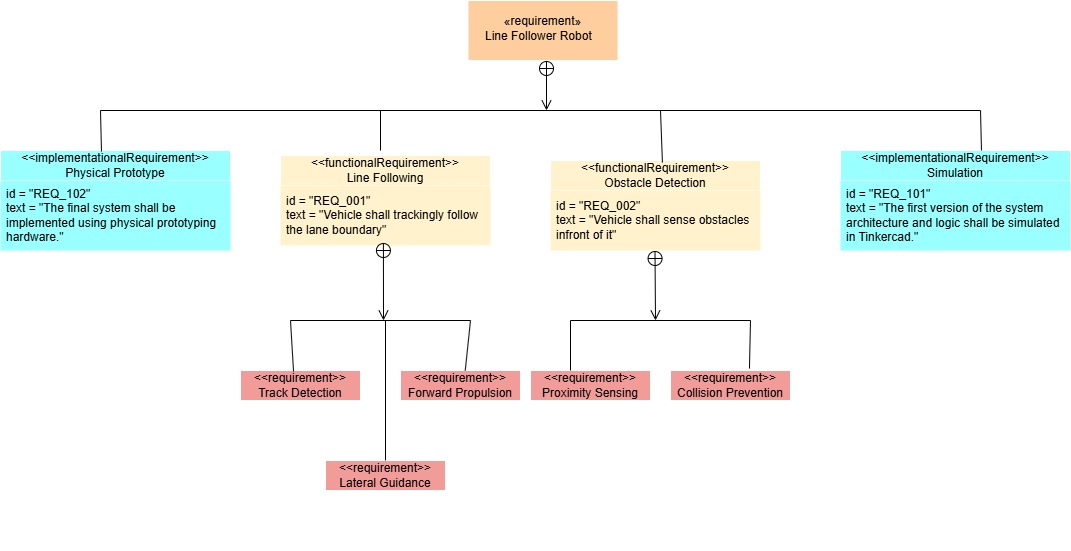
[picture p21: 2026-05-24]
SysML Diagrams/Requirement Diagram.jpg

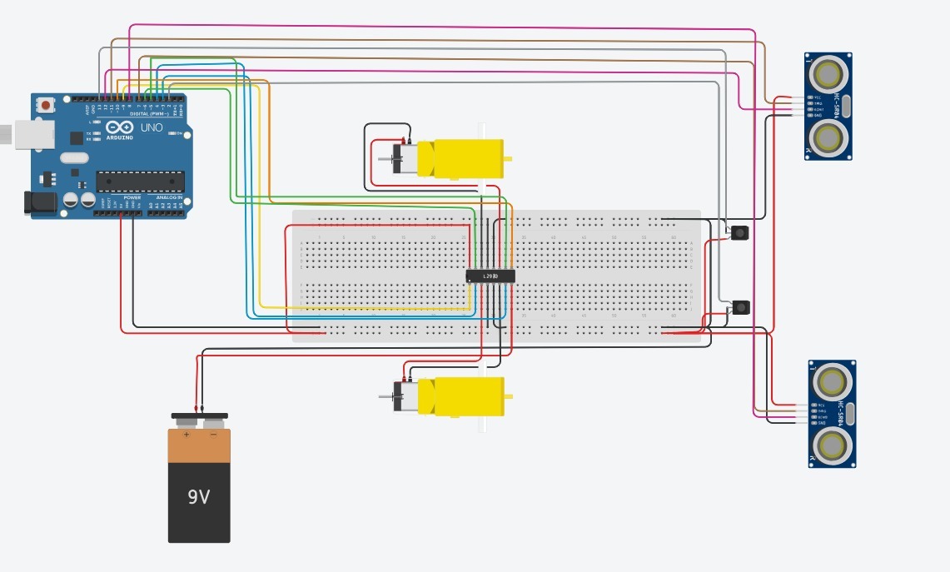
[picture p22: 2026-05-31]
Tinkercad Design/tinkershot.jpg

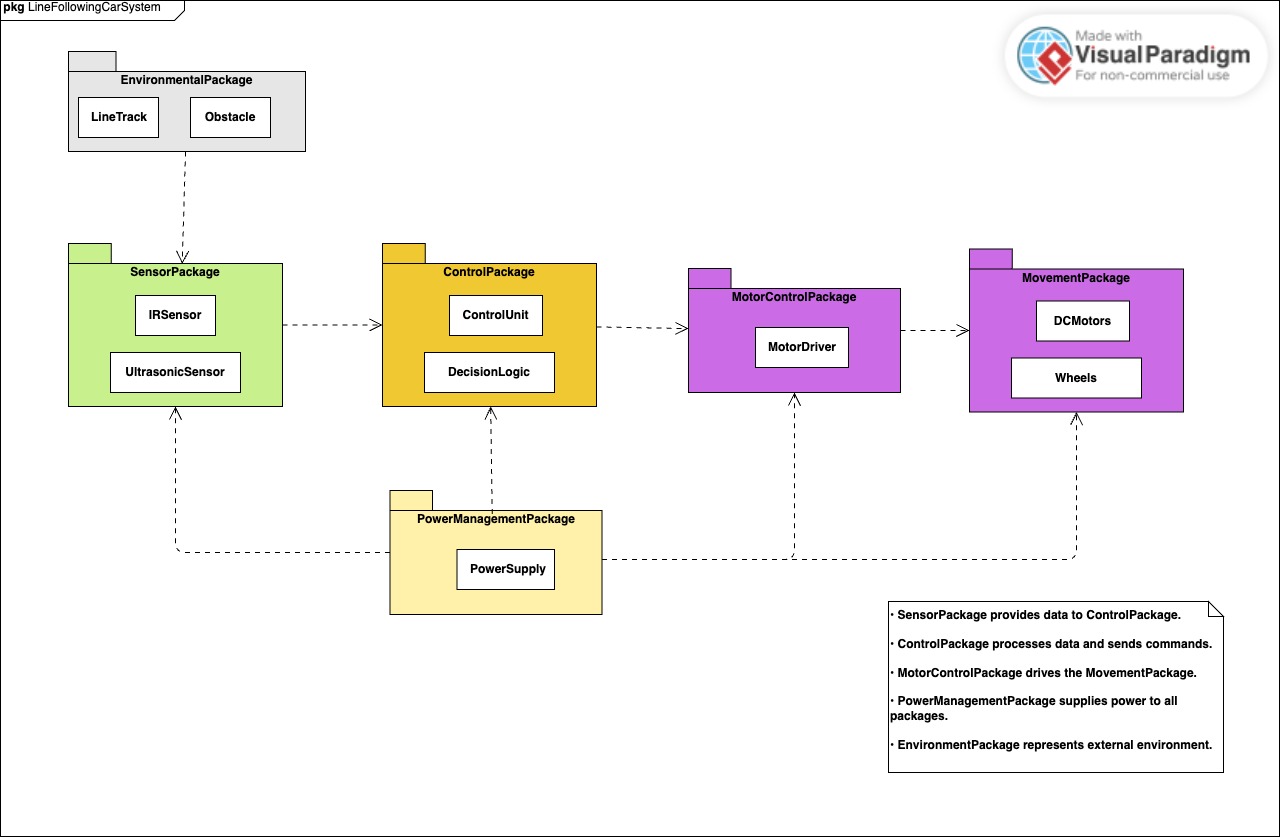
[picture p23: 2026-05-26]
SysML Diagrams/Package Diagram.jpg

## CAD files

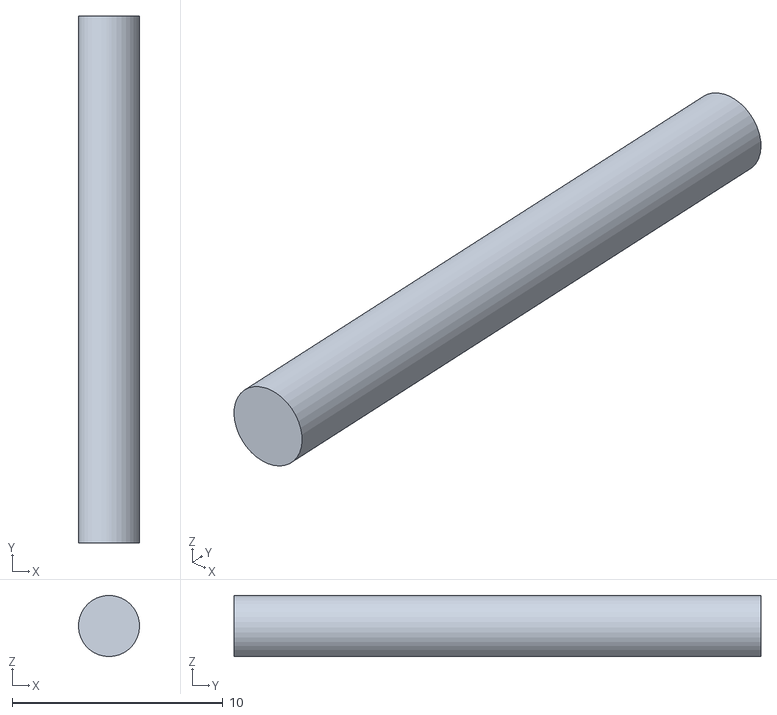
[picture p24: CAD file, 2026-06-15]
Prototype_Design/connector_pin_IR .STL
2.90 x 25.0 x 2.90

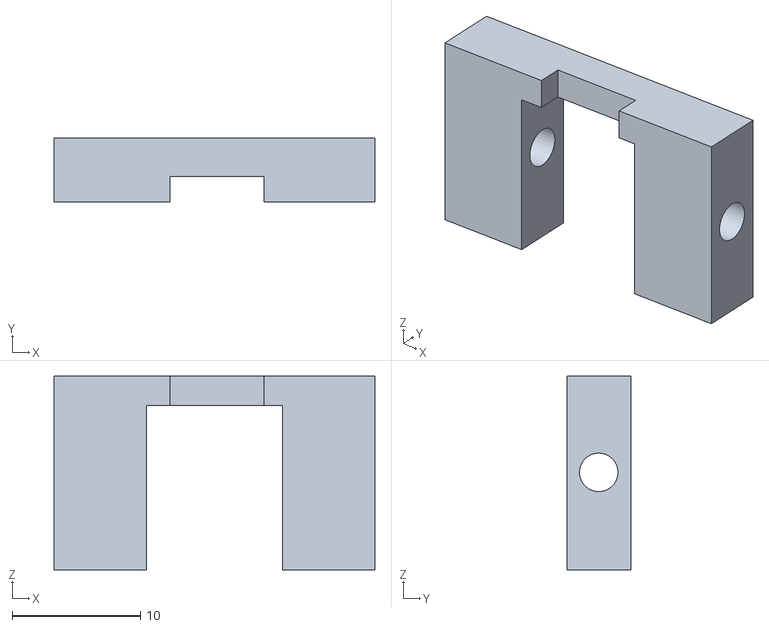
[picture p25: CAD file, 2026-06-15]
Prototype_Design/IR_HOLDER_BOTTOM.STL
25.0 x 5.00 x 15.1

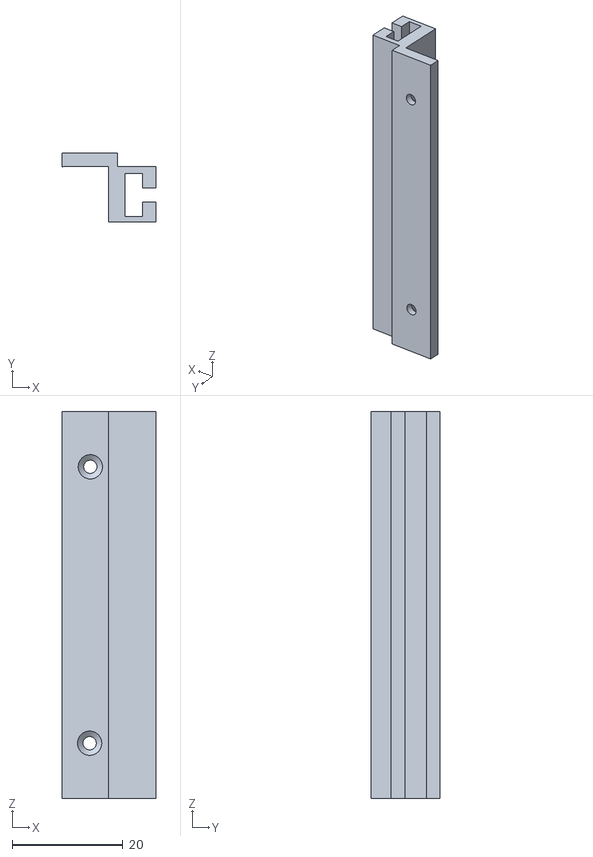
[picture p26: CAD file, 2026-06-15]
Prototype_Design/ir_holders.STL
17.1 x 12.5 x 70.0

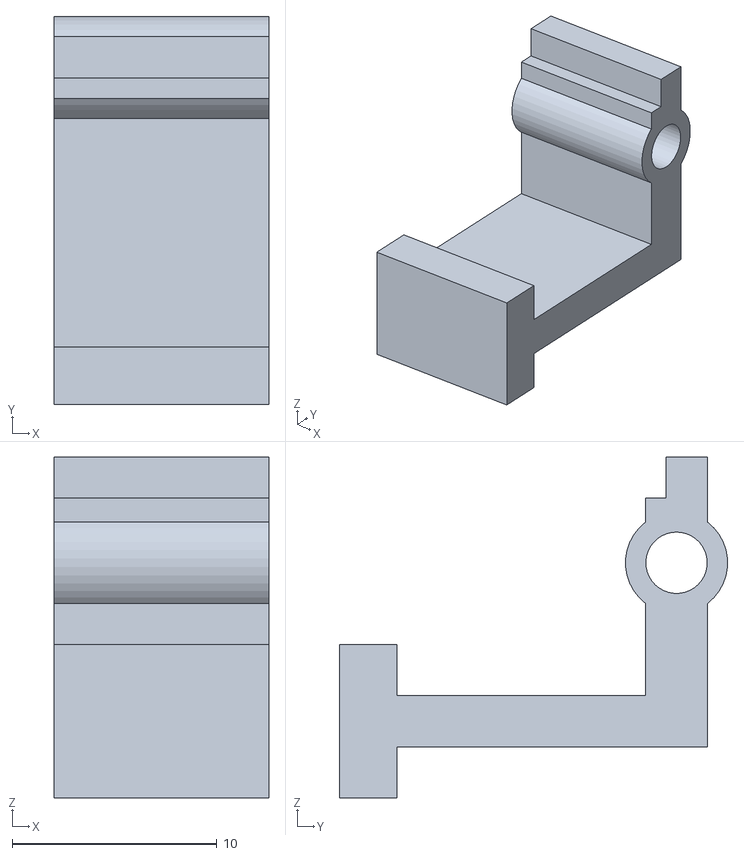
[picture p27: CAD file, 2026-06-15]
Prototype_Design/tshape_ir.STL
10.5 x 19.0 x 16.7

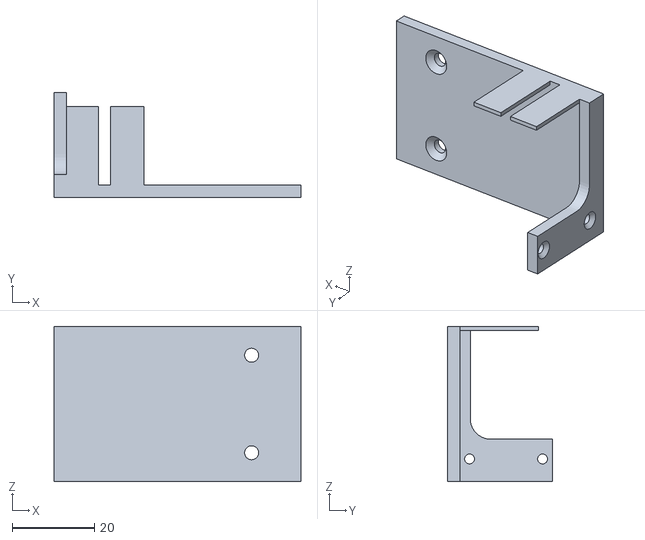
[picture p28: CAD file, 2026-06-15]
Prototype_Design/final_motorholder.STL
60.0 x 25.4 x 37.7

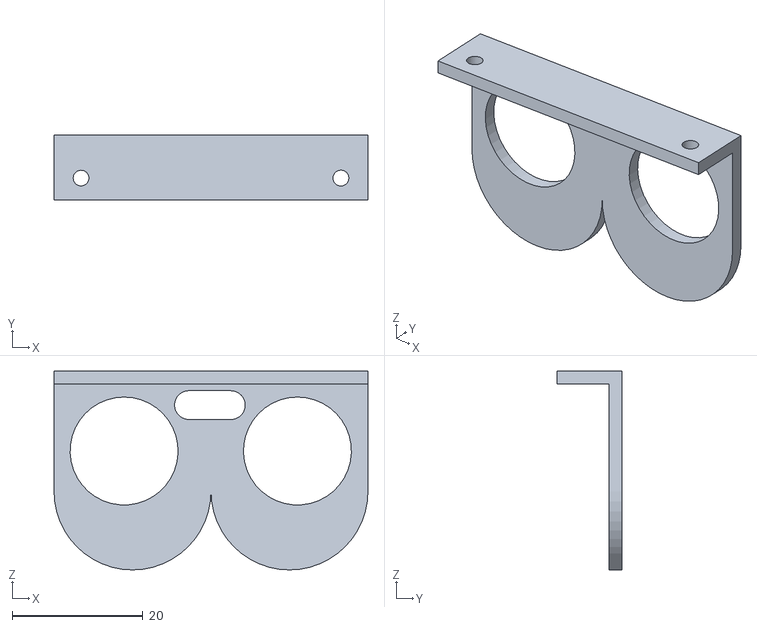
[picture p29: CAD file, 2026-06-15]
Prototype_Design/Ultrasonic_Holder.STL
48.0 x 10.0 x 30.4

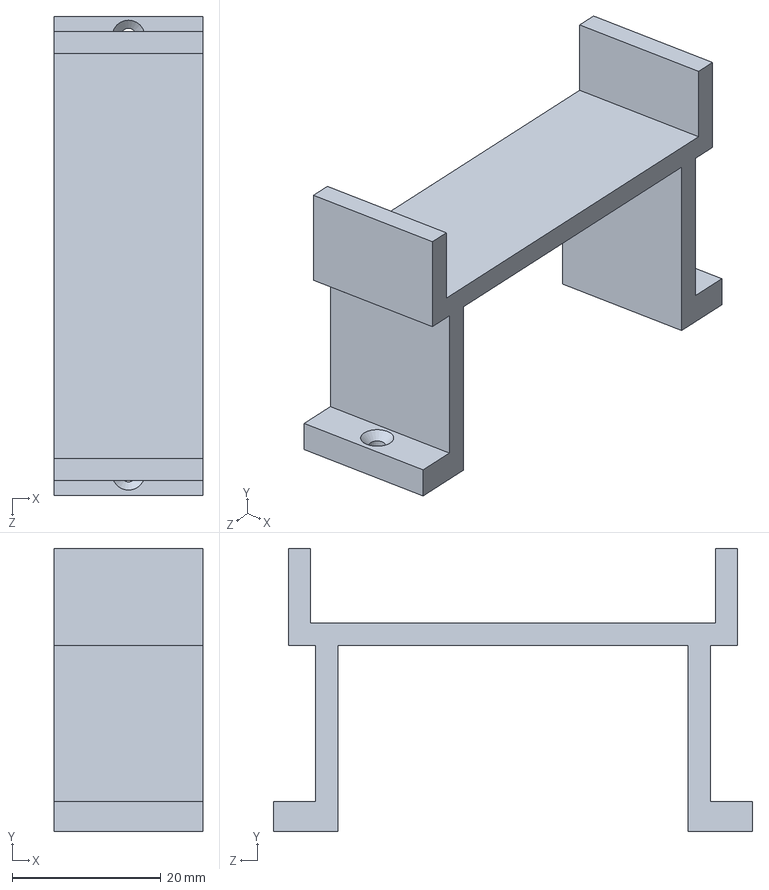
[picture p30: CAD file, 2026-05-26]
Prototype_Design/Battery_Breadboard_Holder_(A3 Team).SLDPRT
20.0 x 38.0 x 64.3 mm

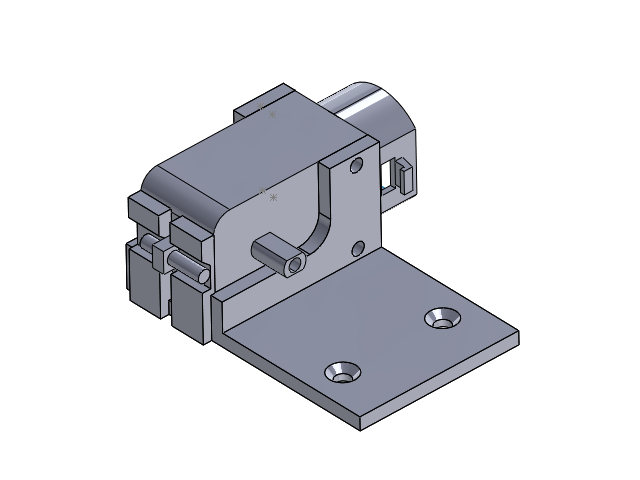
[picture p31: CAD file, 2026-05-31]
Prototype_Design/Assemfinal.SLDASM
motor
final_motorholder
rodadham

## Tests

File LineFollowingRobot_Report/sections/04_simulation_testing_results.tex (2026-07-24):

\section{Simulation and Testing Results}
\label{sec:simulation_testing_results}

\subsection{Experimental Setup}

After completing the hardware and software implementation, the robot was evaluated on a custom test track consisting of a 2.5\,cm wide black line. The track contained both gentle and sharp curves to evaluate the line-following performance under different path conditions. Two obstacles were also positioned along the course to test the obstacle detection, avoidance, and turnaround functions.

The robot was tested repeatedly under similar operating conditions. During each trial, it was required to follow the black line autonomously, detect the first obstacle, execute the avoidance manoeuvre, reacquire the line, detect the second obstacle, perform a 180$^\circ$ turn, and continue navigation without external control.

\subsection{Experimental Results}

Multiple experimental trials were conducted to evaluate the overall performance of the system. The robot successfully followed the predefined line through both gentle and sharp curves. The infrared sensors continuously detected the position of the track and allowed the controller to make the required steering corrections.

When the first obstacle was detected, the ultrasonic sensors triggered the obstacle-avoidance routine. The robot successfully moved around the obstacle, searched for the black line, and resumed normal line-following operation after reacquiring the track.

After passing the first obstacle, the robot continued along the course until the second obstacle was detected. At this stage, the controller executed the programmed 180$^\circ$ turning manoeuvre. The robot then followed the line in the opposite direction as required by the test sequence.

The system was tested many times, and ten successful complete trials were recorded. During these trials, the robot completed the intended navigation sequence without manual intervention, corresponding to a recorded success rate of 100\%.

\begin{table}[ht]
\caption{Experimental Performance Summary}
\centering
\begin{tabular}{ll}
\hline
\textbf{Test Item} & \textbf{Result} \\
\hline
Line following & Successful \\
Gentle curves & Successful \\
Sharp curves & Successful \\
First obstacle detection & Successful \\
Obstacle avoidance & Successful \\
Line reacquisition & Successful \\
Second obstacle detection & Successful \\
180$^\circ$ turning manoeuvre & Successful \\
Complete successful trials & 10 out of 10 \\
Overall success rate & 100\% \\
\hline
\end{tabular}
\label{tab:testing_results}
\end{table}

\subsection{Performance Evaluation}

The experimental results show that the developed robot achieved the main project objectives. The combination of infrared line sensing, ultrasonic obstacle detection, and embedded motor control enabled the robot to navigate the complete test course successfully.

The robot moved at a sufficient operating speed while maintaining stable line-following performance. It was able to respond correctly to both obstacles and recover the track after the avoidance manoeuvre. The successful completion of ten recorded trials indicates that the implemented hardware and software provided reliable autonomous behaviour under the tested conditions.

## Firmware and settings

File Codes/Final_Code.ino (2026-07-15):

// --- Pin Definitions ---
// IR Sensors
const int irLeftPin = 2;
const int irRightPin = 12;

// Ultrasonic Sensors
const int trigLeft = 13;
const int echoLeft = 4;
const int trigRight = 6;
const int echoRight = 7;

// Motor A (Left Motor Control)
const int ena = 3;  // PWM pin for speed
const int in1 = 8;  // Direction pin 1
const int in2 = 9;  // Direction pin 2

// Motor B (Right Motor Control)
const int in3 = 10; // Direction pin 1
const int in4 = 11; // Direction pin 2
const int enb = 5;  // PWM pin for speed

// --- Speed Adjustments ---
const int leftMotorSpeed = 70; 
const int rightMotorSpeed = 79; // Balanced to match left motor's output

// --- Distance Threshold ---
const int obstacleDistance = 24; // 25cm limit

// --- STATE MEMORY ---
// 'F' = Forward, 'L' = Left, 'R' = Right
char lastState = 'F'; 
int obstacleCount = 0; // Initialize to 0 for logical counting

void setup() {
  Serial.begin(9600);

  // Initialize IR Sensors
  pinMode(irLeftPin, INPUT);
  pinMode(irRightPin, INPUT);

  // Initialize Ultrasonic Sensors
  pinMode(trigLeft, OUTPUT);
  pinMode(echoLeft, INPUT);
  pinMode(trigRight, OUTPUT);
  pinMode(echoRight, INPUT);

  // Initialize Motors
  pinMode(ena, OUTPUT);
  pinMode(enb, OUTPUT);
  pinMode(in1, OUTPUT);
  pinMode(in2, OUTPUT);
  pinMode(in3, OUTPUT);
  pinMode(in4, OUTPUT);

  Serial.println("System Initialized (Smart Delay Obstacle Avoidance)...");
}

int getDistance(int trigPin, int echoPin) {
  digitalWrite(trigPin, LOW);
  delayMicroseconds(2);
  digitalWrite(trigPin, HIGH);
  delayMicroseconds(10);
  digitalWrite(trigPin, LOW);
  
  long duration = pulseIn(echoPin, HIGH, 20000); 
  int distance = duration * 0.034 / 2;
  
  return distance;
}

void secondObstacleAction() {
   motorStop();
        delay(500);
  slowspinLeft();
  delay(200); // Give the robot time to move OFF the current line before checking again
  while (digitalRead(irLeftPin) == 0 && digitalRead(irRightPin) == 0) {
    // Let the motors run until a sensor finds the line
    delay(10); 
  }
}

void loop() {
  // 1. Check for obstacles first
  int distanceLeft = getDistance(trigLeft, echoLeft);
  delay(5);
  int distanceRight = getDistance(trigRight, echoRight);

  // 2. OBSTACLE AVOIDANCE "DETOUR" LOGIC
  if ((distanceLeft > 0 && distanceLeft <= obstacleDistance) || 
      (distanceRight > 0 && distanceRight <= obstacleDistance)) {
    
    motorStop();
    delay(50); // Brief pause to let motors settle (reduces electrical noise)
    
    // Read them one more time to verify
    distanceLeft = getDistance(trigLeft, echoLeft);
    delay(30); 
    distanceRight = getDistance(trigRight, echoRight);
    
    // If it STILL sees the obstacle, execute the detour
    if ((distanceLeft > 0 && distanceLeft <= obstacleDistance) || 
        (distanceRight > 0 && distanceRight <= obstacleDistance)) {
          
      obstacleCount++; // Increment the counter no matter what
      
      if (obstacleCount == 2) {
        // Execute the custom function on the 2nd obstacle
        secondObstacleAction();
        return; // Return to the top of the loop after completing the action
      } else {
        motorStop();
        delay(500); 
        
        DriftLeft();
        delay(600);
        
        DriftRight();
        while (digitalRead(irLeftPin) == 0 && digitalRead(irRightPin) == 0) {
          // Let the motors run until a sensor finds the line
          delay(10); 
        }
        
        // Once the loop breaks, at least one sensor found the line!
        return; 
      } 
    } 
  } // <--- THIS CLOSING BRACE WAS MISSING

  // 3. NORMAL LINE FOLLOWING LOGIC (Runs if no obstacle detected)
  int leftSensor = digitalRead(irLeftPin);
  int rightSensor = digitalRead(irRightPin);

  if (leftSensor == 1 && rightSensor == 1) {
    moveForward();
    lastState = 'F';
  } 
  else if (leftSensor == 1 && rightSensor == 0) {
    turnLeft();
    lastState = 'L'; 
  } 
  else if (leftSensor == 0 && rightSensor == 1) {
    turnRight();
    lastState = 'R'; 
  } 
  else if (leftSensor == 0 && rightSensor == 0) {
    // Completely lost the track! Use memory to find it.
    if (lastState == 'L') {
      spinLeft();  
    } 
    else if (lastState == 'R') {
      spinRight(); 
    } 
    else {
      moveForward(); 
    }
  }

  delay(10); 
}

// --- Motor Movement Functions ---
void moveForward() {
  analogWrite(ena, leftMotorSpeed);
  analogWrite(enb, rightMotorSpeed);
  digitalWrite(in1, HIGH);
  digitalWrite(in2, LOW);
  digitalWrite(in3, HIGH);
  digitalWrite(in4, LOW);
}

void slowmoveForward() {
  analogWrite(ena, 70);
  analogWrite(enb, 80);
  digitalWrite(in1, HIGH);
  digitalWrite(in2, LOW);
  digitalWrite(in3, HIGH);
  digitalWrite(in4, LOW);
}

void superslowmoveForward() {
  analogWrite(ena, 74);
  analogWrite(enb, 78);
  digitalWrite(in1, HIGH);
  digitalWrite(in2, LOW);
  digitalWrite(in3, HIGH);
  digitalWrite(in4, LOW);
}

void turnRight() {
  analogWrite(ena, 89);
  analogWrite(enb, 60);
  digitalWrite(in1, HIGH);
  digitalWrite(in2, LOW);
  digitalWrite(in3, HIGH);
  digitalWrite(in4, LOW);
}

void turnLeft() {
  analogWrite(ena, 60); 
  analogWrite(enb, 81);
  digitalWrite(in1, HIGH);
  digitalWrite(in2, LOW);
  digitalWrite(in3, HIGH);
  digitalWrite(in4, LOW);
}

void spinRight() {
  analogWrite(ena, 85);
  analogWrite(enb, 94); 
  digitalWrite(in1, HIGH);
  digitalWrite(in2, LOW);
  digitalWrite(in3, LOW);
  digitalWrite(in4, HIGH);
}

void spinLeft() {
  analogWrite(ena, 85);
  analogWrite(enb, 94); 
  digitalWrite(in1, LOW);
  digitalWrite(in2, HIGH);
  digitalWrite(in3, HIGH);
  digitalWrite(in4, LOW);
}
void slowspinLeft() {
  analogWrite(ena, 68);
  analogWrite(enb, 70); 
  digitalWrite(in1, LOW);
  digitalWrite(in2, HIGH);
  digitalWrite(in3, HIGH);
  digitalWrite(in4, LOW);
}

void motorStop() {
  analogWrite(ena, 0);
  analogWrite(enb, 0);
  digitalWrite(in1, LOW);
  digitalWrite(in2, LOW);
  digitalWrite(in3, LOW);
  digitalWrite(in4, LOW);
}

void DriftLeft() {
  analogWrite(ena, 60);
  analogWrite(enb, 95);
  digitalWrite(in1, HIGH);
  digitalWrite(in2, LOW);
  digitalWrite(in3, HIGH);
  digitalWrite(in4, LOW);
}

void DriftRight() {
  analogWrite(ena, 75);
  analogWrite(enb, 50);
  digitalWrite(in1, HIGH);
  digitalWrite(in2, LOW);
  digitalWrite(in3, HIGH);
  digitalWrite(in4, LOW);
}

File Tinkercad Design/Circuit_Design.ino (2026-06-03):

// --- PIN DEFINITIONS ---

// Master ON/OFF Switch
const int SWITCH_PIN = A0;

// IR Sensors (Line Following)
const int TOP_IR_PIN = 13;    // Left/Top IR Sensor
const int BOTTOM_IR_PIN = 2;  // Right/Bottom IR Sensor

// Top Ultrasonic Sensor
const int TOP_TRIG_PIN = 11;
const int TOP_ECHO_PIN = 12;

// Bottom Ultrasonic Sensor
const int BOTTOM_TRIG_PIN = 7;
const int BOTTOM_ECHO_PIN = 8;

// L293D Motor Driver Signals
const int ENABLE_12_PIN = 9;   // Left Motor Enable (Controls the bottom motor)
const int INPUT1_PIN = 3;      // Bottom Motor (Output 1)
const int INPUT2_PIN = 4;      // Bottom Motor (Output 2)
const int INPUT3_PIN = 5;      // Top Motor (Output 3)
const int INPUT4_PIN = 6;      // Top Motor (Output 4)
const int ENABLE_34_PIN = 10;  // Right Motor Enable (Controls the top motor)

// --- CONSTANTS ---
const int OBSTACLE_THRESHOLD = 20; // Stop distance in centimeters

void setup() {
  // Initialize Serial Monitor for debugging
  Serial.begin(9600);

  // Configure Switch and IR Sensor Pins
  pinMode(SWITCH_PIN, INPUT);
  pinMode(TOP_IR_PIN, INPUT);
  pinMode(BOTTOM_IR_PIN, INPUT);

  // Configure Ultrasonic Pins
  pinMode(TOP_TRIG_PIN, OUTPUT);
  pinMode(TOP_ECHO_PIN, INPUT);
  pinMode(BOTTOM_TRIG_PIN, OUTPUT);
  pinMode(BOTTOM_ECHO_PIN, INPUT);

  // Configure Motor Driver Control Pins
  pinMode(INPUT1_PIN, OUTPUT);
  pinMode(INPUT2_PIN, OUTPUT);
  pinMode(INPUT3_PIN, OUTPUT);
  pinMode(INPUT4_PIN, OUTPUT);
  
  // Configure and activate both H-Bridge Enable channels
  pinMode(ENABLE_12_PIN, OUTPUT);
  pinMode(ENABLE_34_PIN, OUTPUT);
  digitalWrite(ENABLE_12_PIN, HIGH); // Power up bottom motor channel
  digitalWrite(ENABLE_34_PIN, HIGH); // Power up top motor channel
}

void loop() {
  // 1. Check Master Switch Status
  int switchState = digitalRead(SWITCH_PIN);
  
  if (switchState == LOW) {
    // If master switch is OFF, completely halt vehicle operations
    stopMotors();
    Serial.println("System OFF - Switch to ON to start.");
    delay(200); 
    return; // Skip the rest of the loop
  }

  // 2. Measure Distances from Ultrasonic Sensors
  long topDistance = getDistance(TOP_TRIG_PIN, TOP_ECHO_PIN);
  long bottomDistance = getDistance(BOTTOM_TRIG_PIN, BOTTOM_ECHO_PIN);

  // 3. Obstacle Avoidance Logic (Safety Priority)
  if (topDistance < OBSTACLE_THRESHOLD || bottomDistance < OBSTACLE_THRESHOLD) {
    stopMotors();
    Serial.println("OBSTACLE DETECTED! Braking system engaged.");
    delay(100);
    return; // Override line following until path is clear
  }

  // 4. Line Following Logic
  int topIR = digitalRead(TOP_IR_PIN);       // Reads HIGH if tracking line
  int bottomIR = digitalRead(BOTTOM_IR_PIN); // Reads HIGH if tracking line

  if (topIR == HIGH && bottomIR == HIGH) {
    moveForward();
    Serial.println("Path clear: Moving Forward.");
  } 
  else if (topIR == LOW && bottomIR == HIGH) {
    turnRight();
    Serial.println("Deviation detected: Adjusting Right.");
  } 
  else if (topIR == HIGH && bottomIR == LOW) {
    turnLeft();
    Serial.println("Deviation detected: Adjusting Left.");
  } 
  else {
    // Both sensors off the line
    stopMotors();
    Serial.println("Line lost: Stopped.");
  }

  delay(50); // Small stability delay for Tinkercad solver
}

// --- ROBOT MOVEMENT FUNCTIONS ---

void moveForward() {
  digitalWrite(INPUT1_PIN, HIGH);
  digitalWrite(INPUT2_PIN, LOW);
  digitalWrite(INPUT3_PIN, HIGH);
  digitalWrite(INPUT4_PIN, LOW);
}

void turnLeft() {
  // Pivot left: stop left (bottom) motor, drive right (top) motor forward
  digitalWrite(INPUT1_PIN, LOW);
  digitalWrite(INPUT2_PIN, LOW);
  digitalWrite(INPUT3_PIN, HIGH);
  digitalWrite(INPUT4_PIN, LOW);
}

void turnRight() {
  // Pivot right: drive left (bottom) motor forward, stop right (top) motor
  digitalWrite(INPUT1_PIN, HIGH);
  digitalWrite(INPUT2_PIN, LOW);
  digitalWrite(INPUT3_PIN, LOW);
  digitalWrite(INPUT4_PIN, LOW);
}

void stopMotors() {
  digitalWrite(INPUT1_PIN, LOW);
  digitalWrite(INPUT2_PIN, LOW);
  digitalWrite(INPUT3_PIN, LOW);
  digitalWrite(INPUT4_PIN, LOW);
}

// --- ULTRASONIC DISTANCE SENSOR FUNCTION ---
long getDistance(int trigPin, int echoPin) {
  digitalWrite(trigPin, LOW);
  delayMicroseconds(2);
  digitalWrite(trigPin, HIGH);
  delayMicroseconds(10);
  digitalWrite(trigPin, LOW);

  long duration = pulseIn(echoPin, HIGH, 30000); // 30ms timeout
  if (duration == 0) return 999;                 // Return safe distance if timeout occurs
  
  // Convert flight duration to centimeters
  return duration * 0.034 / 2;
}

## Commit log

2026-05-24 Upload Ultrasonic Sensor holder
    [Ultrasonic Holder.SLDPRT]
2026-05-24 Upload Use Case Diagram
2026-06-10 Upload the code of Tinkercad Circuit
2026-06-15 Upload ultrasonic holder design
    [Ultrasonic_Holder.STL]
2026-06-15 Add files via upload
    This is final motorholder that was used ,STL File
    [final_motorholder.STL]
2026-07-16 Updated use case diagram
